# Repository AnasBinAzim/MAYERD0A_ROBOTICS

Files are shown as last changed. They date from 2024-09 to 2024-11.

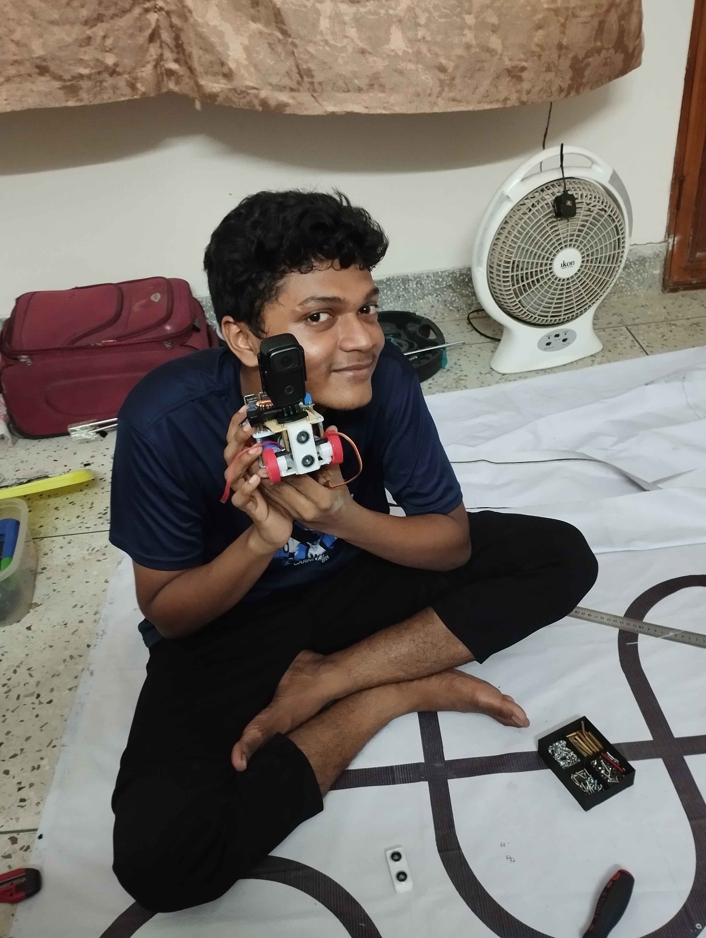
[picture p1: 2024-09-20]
other/TheEpilogue/pookie.jpg

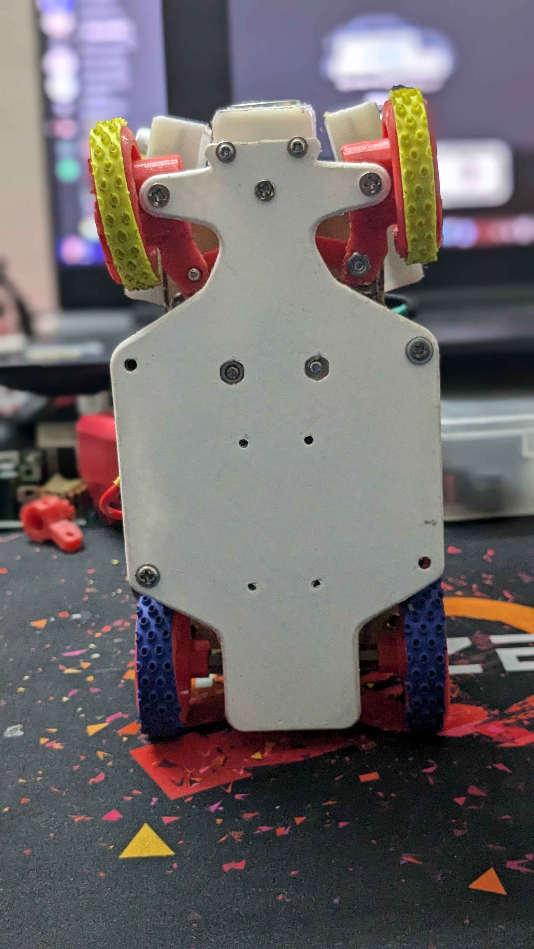
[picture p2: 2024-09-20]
v-photos/bottom_view.jpg

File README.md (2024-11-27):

# 🤖 **MAYERDOA Robotics - WRO 2024 Project** 🤖

<div align="center">
  
</div>

---

## 👥 **Team MAYERDOA - "Mothers' Prayers"**

- **Anas Bin Azim**  – Software & Hardware Developer | [anas.azim.71@gmail.com](mailto:anas.azim.71@gmail.com)
- **Rakibul Islam**  – Team Leader, Primary Hardware Developer | [rakibul.rir06@gmail.com](mailto:rakibul.rir06@gmail.com)
- **Mohiuddin Sami** – Primary Software Developer | [sm.mohiuddin.sami@gmail.com](mailto:sm.mohiuddin.sami@gmail.com)

**Team Origin**: Bangladesh

---

### 🌟 **The Meaning Behind MAYERDOA**

Our team name, "MAYERDOA," means "Mother's Prayers" in Bengali, honoring the constant support and encouragement of our mothers. From the early stages of selection to reaching the global WRO stage, they have been our strongest supporters, always standing by us. Their love and prayers have been our strength, helping us overcome challenges, achieve milestones, and stay motivated through every step of the journey. This project is more than just a technical effort—it’s a reflection of their unwavering belief in us.

---

## 🎉 Project Overview
SMOKI

This repository includes all files, designs, and code for **SMOKI**, our WRO 2024 robot. Below is the folder structure:

## 📂 Structure

Here’s a breakdown of the project folders:

- **[`Software-Setup`](./Software-Setup/)**: Steps for software and hardware setup.
- **[`experiments`](./experiments/)**: Documentation of trials and iterations with previous models.
- **[`models`](./models/)**: Contains 3D models and CAD designs.
- **[`other`](./other/)**: Additional documents and miscellaneous files.
- **[`schematic`](./schematic/)**: Wiring and circuit design diagrams.
- **[`src`](./src/)**: Source code for robot programming.
- **[`t-photos`](./t-photos/)**: Technical images of the robot build.
- **[`v-photos`](./v-photos/)**: Visual photos for aesthetics and showcasing.
- **[`video`](./video/)**: Performance and demo videos of SMOKI.

---

----

## Table of Contents

- <span style="color:blue;">Team MAYERDOA - "Mothers' Prayers"</span>
- <span style="color:green;">Mission Overview for WRO Future Engineers Rounds</span>
- <span style="color:orange;">Components and Hardware</span>
- <span style="color:purple;">Assembly Instructions</span>
- <span style="color:red;">Project Objective</span>
- <span style="color:teal;">Mobility Management</span>
- <span style="color:navy;">Power and Sense Management</span>
- <span style="color:brown;">Program Infrastructure and Explanation of Algorithm</span>
- <span style="color:darkgreen;">Software Setup</span>

Our bot, **SMOKI**, is built for excellence in the **World Robot Olympiad 2024** in the Future Engineers category. From its structural core using LEGO Technic elements to its computing capabilities powered by the **Raspberry Pi 4B** and **ESP32 microcontroller**, SMOKI is crafted to handle the nuanced challenges of autonomous navigation and obstacle handling.

---

### Mission Overview for WRO Future Engineers Rounds

<table>
  <tr>
    <td width="50%" valign="top" align="left">
      <h3>🏁 Round 1: Lap Completion</h3>
      <p>In <strong>Round 1</strong>, the robot must autonomously complete <strong>three laps</strong> on a pre-defined track. The goal of this round is for the bot to demonstrate stable navigation and precise lap tracking without any obstacle avoidance requirements.</p>
      <ul>
        <li><strong>Objective</strong>: Complete three laps on the track within the allotted time.</li>
        <li><strong>Key Tasks</strong>: Accurate path-following, speed control, and lap counting.</li>
      </ul>
      <div align="center">
        <br><br><br><br><br>
        Round 1 WRO Track
      </div>
    </td>
    <td width="50%" valign="top" align="left">
      <h3>🏆 Round 2: Lap Completion with Obstacle Avoidance and Parking</h3>
      <p>In <strong>Round 2</strong>, the bot must complete <strong>three laps</strong> while avoiding green and red obstacles:</p>
      <ul>
        <li><strong>Green Obstacles</strong>: The bot should move <strong>left</strong> to avoid.</li>
        <li><strong>Red Obstacles</strong>: The bot should move <strong>right</strong> to avoid.</li>
      </ul>
      <p>After completing the laps, the bot must accurately park within a designated zone.</p>
      <ul>
        <li><strong>Objective</strong>: Complete three laps, avoid obstacles, and park in the designated area.</li>
        <li><strong>Tasks</strong>: Obstacle detection, color-based avoidance, and precision parking.</li>
      </ul>
      <div align="center">
        Round 2 WRO Track
      </div>
    </td>
  </tr>
</table>

---
>[!IMPORTANT]
>**Important: WRO Future Engineers Rulebook**
>* **Thorough Reading:** Ensure that you thoroughly read the **WRO Future Engineers 2024 Rulebook** to understand all rules and guidelines.
>* **Official Link:** Access the rulebook here: [🔗 WRO Future Engineers 2024 Rulebook](https://wro-association.org/competitions/future-engineers/).

---
---

## 🧩 Components and Hardware

Our bot is equipped with various components that support its autonomous functionality. Here is a breakdown of the key hardware elements used in this project:

| Component | Description | Image | Purchase Link |
|---|---|---|---|
| **Raspberry Pi 4B** | Provides processing power for control algorithms and sensor data management. | <div align="center">Raspberry Pi 4B</div> | [Purchase Raspberry Pi 4B](https://amzn.to/3wKg5TG) |
| **ESP32 Microcontroller** | Handles real-time sensor data interpretation and motor control. | <div align="center">ESP32</div> | [Purchase ESP32](https://amzn.to/3ESP32) |
| **LEGO EV3 Expansion Set (45560)** | Modular components used for building and structural support. | <div align="center">LEGO EV3 Set</div>  | [Purchase LEGO 45560](https://amzn.to/3K4eLEGO) |
| **XL4016 Buck Converter** | Provides stable voltage for the Raspberry Pi and ESP32, enhancing power management. | <div align="center">XL4016 Buck Converter</div> | [Purchase XL4016](https://amzn.to/4xl4016) |
| **Custom PCB** | Custom-designed PCB for efficient wiring and stable connections across all components. | <div align="center">Custom PCB</div> | N/A |
| **Ultrasonic Sensors** | Detects distances to obstacles and aids in precise navigation. | <div align="center">Ultrasonic Sensor</div> | [Purchase Ultrasonic Sensor](https://amzn.to/3Ultrasonic) |
| **Webcam - FIFINE K420 HD** | Captures visual data, supporting navigation and obstacle detection tasks. | <div align="center">FIFINE K420 HD Webcam</div> | [Purchase FIFINE K420 HD Webcam](https://amzn.to/3FifineK420) |
| **Gyroscope - MPU 6050** | Provides motion tracking and orientation data, enabling stable navigation and movement. | <div align="center">MPU 6050</div> | [Purchase MPU 6050](https://amzn.to/3MPU6050) 
| **Battery - GENS 1000mAh** | Supplies power to the robot, ensuring long operational time and reliable energy for all components.|  | [Buy GENS ACE 11.1V 3S LiPo Battery](https://www.rcshopbd.com/product/gens-ace-11-1v-3s-lipo-1000mah-1650mah-2200mah-3300mah-battery/)

---

## 🚀 Key Features

- **Modular LEGO Design**: Easily reconfigurable using LEGO Technic parts, allowing for quick adjustments.
- **Advanced Processing with Raspberry Pi 5**: Enables complex algorithms and sensor data handling.
- **Efficient Power Management**: The XL4016 buck converter and custom PCB provide stable voltage.
- **Comprehensive Sensor Suite**: Includes ultrasonic and infrared sensors for precision navigation.
- **3D Printed Mounts**: Ensures stable and adaptable sensor and component placement.

---

## 🔧 Assembly Instructions

### 🏗️ Chassis Assembly - LEGO 45560 Expansion Set

Our robot’s chassis is built using components from the **LEGO Technic Expansion Set 45560**. This set provides modular, robust, and flexible building parts that are ideal for constructing a stable and durable chassis foundation. The combination of LEGO’s high-quality materials and custom components ensures that our robot is adaptable, allowing for quick adjustments and additions.

#### 📘 LEGO 45560 Expansion Set Manual
For a step-by-step guide on using the LEGO 45560 parts, refer to the official **LEGO 45560 Expansion Set Manual**:
- **[LEGO 45560 Expansion Set Manual (PDF Download)](https://www.lego.com/cdn/manuals/45560.pdf)**

---

#### 🧩 Parts List - LEGO 45560 Expansion Set

The LEGO 45560 Expansion Set contains a variety of parts that are essential for building complex mechanisms. Below is a detailed list of all parts included in the set:

| Part Number | Part Name | Quantity |
|---|---|---|
| 45502 | LEGO Technic Beam 3x5 | 2 |
| 45503 | LEGO Technic Beam 3x7 | 4 |
| 45504 | LEGO Technic Beam 5x11 | 2 |
| 45505 | LEGO Technic Beam 5x7 | 4 |
| 45507 | LEGO Technic Beam 1x9 | 6 |
| 45508 | LEGO Technic Beam 1x15 | 4 |
| 45509 | LEGO Technic Angular Beam 4x6  | 6 |
| 45510 | LEGO Technic Angular Beam 3x5  | 4 |
| 3703 | LEGO Technic Beam 1x16 | 2 |
| 32000 | LEGO Technic Brick 1x14 | 4 |
| 32002 | LEGO Technic Cross Block 3x3 | 4 |
| 92907 | LEGO Technic Axle 7 | 8 |
| 32009 | LEGO Technic Axle 9 | 4 |
| 24316 | LEGO Technic Gear 24 Tooth | 4 |
| 42003 | LEGO Technic Gear 16 Tooth | 6 |
| 6538b | LEGO Technic Connector Peg w/ Friction | 50 |
| 3647 | LEGO Technic Gear 8 Tooth | 6 |
| 87083 | LEGO Technic Pin 2L | 60 |
| 32269 | LEGO Technic Connector Peg | 20 |
| 40490 | LEGO Technic Axle Pin | 40 |
| 32556 | LEGO Technic Double Cross Block | 6 |
| 32184 | LEGO Technic Connector with Bush | 8 |
| 3749 | LEGO Technic Bush | 40 |
| 3713 | LEGO Technic Half Bush | 30 |
| 42195 | LEGO Technic Pin w/ Stop | 12 |
| 18654 | LEGO Technic Angular Beam 4x4  | 6 |
| 11478 | LEGO Technic Frame 5x7 | 2 |

> **Note**: Quantities are approximate based on the LEGO 45560 set contents. For exact counts, refer to the [manual](https://www.lego.com/cdn/manuals/45560.pdf).

---

#### 🛠️ Chassis Assembly Process

Here’s a step-by-step overview of the chassis assembly process using the LEGO 45560 Expansion Set:

1. **Base Frame Construction**: Start by assembling the base frame using 5x11 and 5x7 beams for structural stability. These beams provide a strong foundation for mounting additional components.
2. **Motor and Axle Integration**: Utilize the LEGO Technic beams and axle connectors to securely attach the motors. Ensure proper alignment to enable smooth and controlled movement.
3. **Reinforcing with Angular Beams**: Use the 4x6 and 3x5 angular beams to reinforce corners and support areas where weight and stress are concentrated.
4. **Mounting Sensors and Electronics**: Attach sensor mounts and electronic components using cross blocks and bushings, making sure they are aligned for efficient data capture and processing.
5. **Gear Assembly for Differential Drive**: Assemble gears (8, 16, and 24-tooth gears) to create a differential drive system, allowing independent rotation of wheels for smooth turns.

---

#### 🔍 Benefits of Using LEGO Technic Parts

- **Modularity**: The LEGO Technic beams and connectors allow for quick modifications, so adjustments can be made without disrupting the entire structure.
- **Durability**: High-quality materials ensure the chassis remains stable even during rigorous testing.
- **Precision**: Technic gears, axles, and connectors provide precise alignment, which is critical for movement control and sensor accuracy.

---

By leveraging the flexibility and durability of the LEGO 45560 Expansion Set, our chassis design achieves a balance between robustness and adaptability. The manual and parts list serve as valuable resources for replicating or modifying the design as needed.

---

The following images showcase the detailed assembly process of our WRO Bot's chassis, utilizing the LEGO 45560 expansion set.

<!DOCTYPE html>
<html lang="en">
<head>
  <meta charset="UTF-8">
  <meta name="viewport" content="width=device-width, initial-scale=1.0">
</head>
<body>
  <table style = "width:100%; border-collapse:collapse">
    <caption><strong>Framed Images</strong></caption>
    <tr>
      <td></td>
      <td></td>
    </tr>
    <tr>
      <td></td>
      <td></td>
    </tr>
    <tr>
      <td></td>
      <td></td>
    </tr>
    <tr>
      <td colspan="2"></td>
    </tr>
  </table>
</body>
</html>

### 🚗 Drive System

The drive system includes DC motors, which provide reliable propulsion and control.

<p align="center">
  <table>
    <tr>
      <td>
        
      </td>
      <td>
        
      </td>
    </tr>
    <tr>
      <td>
        
      </td>
      <td>
        
      </td>
    </tr>
  </table>
</p>

----

# 🚗 Mobility Management

This segment goes over the mobility management of SMOKI
---

### **Rear Axle Power Distribution**

Initially, the rear wheels were powered through a **Bevel Gear**, but we later upgraded to a **Differential Gearbox** to improve efficiency and performance during turns.

---

#### **Bevel Gear**

<table>
<tr>
<td width="50%">
<div align="center">
  
</div>
</td>
<td width="50%">

A **bevel gear** is a type of gear where the axes of the two shafts intersect, and the tooth-bearing faces of the gears are conical. Bevel gears are commonly used to transfer motion between intersecting shafts at an angle, typically 90°.

##### **How Bevel Gears Work**
- A driver gear transfers motion to a driven gear, which rotates an output shaft.
- The teeth of the gears are designed to mesh smoothly, transferring torque efficiently between the shafts.

##### **Advantages of Bevel Gears**
1. **Compact Design**: Suitable for space-constrained applications.
2. **Efficient Torque Transfer**: Provides reliable power transmission at angles.
3. **Versatility**: Can operate at angles other than 90° if needed.

</td>
</tr>
</table>

---
>[!IMPORTANT]
> Bevel gears were essential in the initial stages of our design, but they had limitations in terms of energy efficiency during turns.
---

#### **Differential Gearbox**

<table>
<tr>
<td width="50%">

A **differential gearbox** allows the wheels on the same axle to rotate at different speeds while receiving power from a single motor. This is crucial for smooth turning, where the outer wheel must travel a larger distance than the inner wheel.

##### **Advantages of Differential Gearbox**
1. **Smooth Turns**: Adapts to varying wheel speeds, ensuring efficient cornering.
2. **Energy Efficiency**: Reduces energy wastage by minimizing wheel slippage.
3. **Component Longevity**: Minimizes wear on tires and axles.

##### **How Differential Gears Work**
- Power from the motor is delivered to an input shaft.
- The differential splits the torque between the two wheels via bevel or spider gears inside the housing.
- During turns, the differential allows one wheel to spin faster than the other, ensuring smooth movement.

</td>
<td width="50%">
<div align="center">
  
</div>
</td>
</tr>
</table>

---

#### **Comparison: Bevel Gear vs. Differential Gearbox**

| **Feature** | **Bevel Gear** | **Differential Gearbox** |
|---|---|---|
| **Turning Efficiency** | Limited; fixed wheel speeds. | Superior; wheels rotate independently. |
| **Energy Usage** | Higher due to slippage during turns. | Lower; optimized for dynamic turns. |
| **Durability** | Higher strain on components. | Reduced strain; longer component life. |

---

### **Servo Motor with L293D Motor Driver**

<table>
<tr>
<td width="30%">
<div align="center">
  
</div>
</td>
<td width="70%">

We used the **L293D Motor Driver** in combination with a **Servo Motor** to control the robot's wheels effectively. We are using **L293D Motor Driver** to control the rear axle motor. The L293D is a dual H-Bridge motor driver that is perfectly suited for the LEGO motor, which operates at **750mA** current.

##### **Why L293D?**
- **Optimal Current Capacity**: Can handle up to **1A** peak current, suitable for the LEGO motor’s 750mA requirement.
- **Bidirectional Control**: Facilitates forward and backward motion of the wheels.
- **Compact and Lightweight**: Ideal for small-scale robotic systems.
- **PWM Support**: Enables smooth speed control of the motors.

##### **Advantages of the Servo Motor with L293D**
1. **Accurate Steering**: The servo motor ensures precise angle adjustments.
2. **Smooth Speed Control**: PWM functionality provides variable speed control.
3. **Efficient Current Management**: Matches the LEGO motor's current needs, ensuring reliable operation.

</td>
</tr>
</table>

---

### **Steering Systems**

Our robot initially used the **Ackermann Steering System**, known for its efficiency in real-world vehicles. However, we later transitioned to the **LEGO Steering System** to simplify the design and improve modularity while maintaining effective steering control.

---

#### **What is Ackermann Steering System?**

The **Ackermann Steering System** ensures that the wheels of a vehicle turn at different angles during a corner. The inner wheels turn more sharply than the outer wheels, reducing tire slippage and allowing smooth, efficient turning.

##### **How Ackermann Steering Works**
- The front wheels are connected via a set of steering arms.
- These arms are angled so that their lines meet at the center of the turn’s radius, ensuring concentric paths for all wheels.

##### **Advantages of Ackermann Steering**
1. **Efficient Turning**: Minimizes tire slippage.
2. **Energy Savings**: Reduces power loss caused by wheel drag.
3. **Realistic Simulation**: Mirrors real-world vehicle steering.

---

#### **Why We Switched to LEGO Steering System**

The **LEGO Steering System** offered greater simplicity and modularity, which were critical for our robot’s design. While Ackermann Steering is ideal for large-scale vehicles, the LEGO system provided better adaptability for our compact robot.

---

#### **What is LEGO Steering System?**

The LEGO Steering System uses modular LEGO Technic parts with a simple rack-and-pinion mechanism for steering. It achieves a turning angle of **50 degrees**, allowing precise control over the robot's movements.

##### **Advantages of LEGO Steering**
1. **Modularity**: Easy to assemble, adjust, and maintain.
2. **Compact Design**: Fits seamlessly into the robot’s chassis.
3. **Precision**: Allows accurate steering movements with a servo motor.
4. **Ease of Use**: Simplifies the overall system design without sacrificing functionality.

---
---

### **Conclusion**

The upgrades to our robot’s mobility system—switching from bevel gears to a differential gearbox, integrating the L293D with a servo motor, and transitioning from  a 3D printed steering mechanism to a steering mechanism using LEGO parts—significantly enhanced its performance. These changes provided:
1. **Smoother Turns**: Differential gearbox enabled independent wheel speeds, reducing slippage.
2. **Precise Control**: The L293D motor driver ensured smooth speed and direction management.
3. **Simpler Design**: LEGO Steering’s modularity allowed for easier integration and maintenance.
4. **Energy Efficiency**: Reduced strain on components, improving energy usage and longevity.

Together, these upgrades ensured that our robot was optimized for the challenges of the WRO course, achieving a balance between simplicity and performance.

----
----
----

# ⚡ Power and Sense Management :

The **Power and Sense Management** system of our robot has been meticulously designed to optimize performance while ensuring reliable power delivery, precise sensing, and efficient communication between components.

## 📜 Overview
The power system ensures all components receive stable and efficient power tailored to their unique voltage and current requirements. This design optimizes energy utilization and guarantees reliability under various operational loads.

---

## ⚙️ System Architecture

### **1. Power Source: Two Lithium-Ion Cells**
- **Configuration**: Two 4.2V lithium-ion cells connected in series.
- **Total Voltage**: 8.4V when fully charged, dropping to ~6V when discharged.
- **Features**:
  - High energy density for extended runtime.
  - Lightweight and rechargeable.

---

### **2. XL4016 Buck Converter**
- **Input**: 8.4V from the battery pack.
- **Output**: Stable 5V for the **Raspberry Pi 5** and other components.
- **Specifications**:
  - Input Voltage Range: Up to 40V.
  - High efficiency (~90%) for minimal heat generation.
- **Usage**:
  - Powers the Raspberry Pi 4B to ensure stable performance for real-time processing tasks.

---

### **3. Additional Buck Converters**
#### **(a) 5V Buck Converter for Servo Motor**
- **Purpose**: Supplies 5V for the **Servo Motor**.
- **Key Benefits**:
  - Ensures optimal torque and speed for motor operations.
  - Prevents jitter or underperformance caused by unstable power.

#### **(b) 5V Buck Converter for ESP32**
- **Purpose**: Supplies 5V for the **ESP32 Microcontroller**.
- **Features**:
  - Powers the ESP32 for communication (Wi-Fi and Bluetooth).
  - Protects against overvoltage, ensuring stable and reliable operation.

---

### **4. Buck-Boost Converter for Motors**
- **Purpose**: Provides a consistent 12V for the motors, regardless of battery voltage variations.
- **How It Works**:
  - Boosts the voltage when input drops below 12V (e.g., batteries discharged to 6V).
  - Steps down the voltage if the input exceeds 12V.
- **Benefits**:
  - Delivers reliable motor performance under various loads.
  - Prevents voltage-related motor performance issues.

---

## 🔌 Voltage Distribution Table

| Component | Voltage Supplied | Converter Type |
|---|---|---|
| **Raspberry Pi 4B** | 5V | XL4016 Buck |
| **Servo Motor** | 5V | Buck Converter |
| **ESP32 Microcontroller**| 5V | Buck Converter |
| **Motors** | 12V | Buck-Boost Converter|

---

## 🔧 Installation and Configuration

1. **Connect the Lithium-Ion Cells**:
   - Use a **series connection** to achieve 8.4V.
   - Ensure a proper battery management system (BMS) to prevent overcharging or deep discharging.

2. **Setup XL4016 Buck Converter**:
   - Adjust the output voltage to 5V using the onboard potentiometer.
   - Connect the output to the Raspberry Pi 5 power input.

3. **Install Buck Converters**:
   - **5V Converter for Servo Motor**:
     - Configure the output voltage to 5V for the servo motor.
     - Connect the output to the servo's power input.
   - **5V Converter for ESP32**:
     - Configure the output voltage to 5V for the ESP32 microcontroller.
     - Connect the output to the ESP32's power input.

4. **Configure Buck-Boost Converter**:
   - Set the output to 12V.
   - Connect the output to the motor driver’s power input.

5. **Test Voltage Levels**:
   - Use a multimeter to verify output voltages for each converter before powering the components.

---

## 🛠 Maintenance Tips
- **Regularly Check Connections**:
  - Ensure tight and secure connections to avoid power interruptions.
- **Monitor Battery Levels**:
  - Recharge the lithium-ion cells when the voltage drops below 6V.
- **Inspect Converters**:
  - Periodically check for overheating or loose components on the converters.

---

## 🚀 Future Improvements
- Integrate a smart power monitoring system to dynamically adjust power distribution.
- Upgrade to more energy-efficient components as technology advances. ( WE WILL BE AROUND HOPEFULLY)

---
## 🎥 Camera Placement and Functionality

The robot's main camera is positioned at the top and angled slightly downwards. This setup enhances object detection capabilities by providing:
- **🔍 Close-Range Detection**: The camera can identify objects in close proximity with high accuracy.
- **🌐 Extended-Range Detection**: Ensures objects further away are detected effectively.

The camera feeds data to the **Raspberry Pi 5**, which processes image recognition algorithms to detect towers and corner lines. The processed data is then transmitted to the **ESP32 microcontroller** for real-time navigation and obstacle avoidance.

---

## 📡 Sonar Mount Design

### 🛠️ Previous Design
In our earlier design, we used **HC-SR04 sonar sensors** placed at **45-degree angles**, mounted horizontally on two sides of the robot, with one sensor placed vertically in the middle. This configuration provided basic obstacle detection but had limitations:
- **🚫 Blind Spots**: The horizontal placement created gaps in detection range at certain angles.
- **⚠️ Inconsistent Readings**: The 45-degree angle sometimes caused inaccuracies due to signal reflections.

### 🔄 Why We Switched
After analyzing performance during testing, we made significant improvements:
- Replaced the 45-degree sensors with sensors mounted at **15 degrees**.
- Mounted the sensors **vertically on all sides**, ensuring:
  - **🛑 Improved Obstacle Detection**: Enhanced accuracy and coverage around the robot.
  - **📏 Better Range Consistency**: Reduced signal reflection issues for more reliable readings.

### 🚀 Current Design
The new configuration leverages **HC-SR04 sonar sensors**, chosen for their **wide availability** and **affordable price**. The updated design provides:
- **High Coverage**: Vertical mounting eliminates blind spots.
- **Early Detection**: Enhanced obstacle sensing allows for quicker decision-making.
- **Really Cheap**: You can buy 300 of these instead of a Lider Sensor.

---

>[!IMPORTANT]
> **Power Highlights:**
> - The XL4016 Buck Converter ensures stable voltage regulation, critical for protecting the Raspberry Pi and ESP32 microcontroller during operation.
> - Independent buck modules handle the servo motor and ESP32 power needs, optimizing energy usage across all components.

---
---

## 🛠️ Our PCB is custom made. The schematics are in the schematic folder 

---
# Project Name

## 🖼️ System Visuals

### PCB Views

| **Top View of PCB** | **Bottom View of PCB** |
|---|---|
|  |  |

### Power Management Diagram

DIAGRAM

---
---

# 🧠 Program Infrastructure and Explanation ## 🏁 Round 1 Algorithm - Lap Completion

In **Round 1**, our robot **SMOKI** must autonomously complete **three laps** on a predefined track without the need for obstacle avoidance. To achieve precise navigation and lap counting, we have developed a robust algorithm that integrates image processing with control systems.

---

### 🌐 Algorithm Overview

1. **📸 Image Acquisition**:
   - The robot captures real-time images of the track using its onboard camera.

2. **🎨 Color Space Conversion**:
   - Captured images are converted from the **RGB** color space to the **HSV (Hue, Saturation, Value)** color space.
   - The HSV color space is chosen for its effectiveness in color segmentation, as it is less sensitive to lighting variations.

3. **🔍 Color Segmentation and Orientation Determination**:
   - Using predetermined HSV ranges, the algorithm isolates the **blue** and **orange** line segments on the track.
   - During the first run, the robot checks whether the blue line appears before the orange line or vice versa.
   - **Orientation Determination**:
     - If the blue line comes before the orange line, the robot sets its orientation accordingly.
     - This initial orientation check ensures the robot follows the track in the correct direction.

4. **📏 Line Detection and Lap Counting**:
   - The **Hough Line Transform** method is applied to detect lines within the segmented images.
   - The robot counts the detected lines to keep track of laps.
   - **Lap Completion**:
     - After counting **12 lines** (corresponding to three laps), the robot initiates a predetermined delay and then stops.

5. **⚙️ Position Correction Using PID Control**:
   - Before setting the orientation, a **PID (Proportional-Integral-Derivative) controller** calculates the error.
   - **Error Calculation**:
     - The error is determined by the difference between the distances measured by sensors on the left and right sides of the robot (i.e., `error = left_distance - right_distance` or vice versa).
   - **Distance Maintenance**:
     - If the orientation is **right-based**, the robot maintains a **25 cm** distance from the right side.
     - If the orientation is **left-based**, it maintains a **25 cm** distance from the left side.
   - The PID controller adjusts the robot's steering to minimize the error, helping it stay centered on the track.

---

### 📖 Detailed Explanation

#### 1. 📸 Image Acquisition and Preprocessing

- **Camera Input**:
  - High-resolution images are captured at regular intervals to ensure up-to-date visual data.
- **HSV Conversion**:
  - Conversion to HSV allows for more effective color thresholding.
  - HSV separates image intensity (Value) from color information (Hue and Saturation), making it easier to detect specific colors under varying lighting conditions.

#### 2. 🎨 Color Segmentation

- **HSV Thresholding**:
  - Specific HSV ranges for blue and orange are defined based on calibration.
  - **Blue Line Detection**:
    - Pixels within the blue HSV range are extracted.
  - **Orange Line Detection**:
    - Pixels within the orange HSV range are extracted.
- **Orientation Check**:
  - By analyzing the sequence of color segments (blue vs. orange), the robot determines its starting orientation.
  - This prevents incorrect lap counting due to starting in the wrong direction.

#### 3. 📏 Line Detection with Hough Transform

- **Edge Detection**:
  - Preprocessing steps like Gaussian blur and Canny edge detection are applied to enhance line features.
- **Hough Line Transform**:
  - Detects straight lines by transforming points in image space to a parameter space.
  - Lines are identified based on the accumulation of intersecting points in the parameter space.
- **Lap Counting Logic**:
  - Each detected line crossing increments a counter.
  - The robot recognizes lap completion after counting **12** line crossings, accounting for both blue and orange lines over three laps.

<div align="center">
  <!-- Placeholder for Hough Line Transform Image -->

  Hough Line Transform
  <p><em>Figure: Visualization of Hough Line Transform applied to track image.</em></p>
</div>

#### 🔗 **Hough Line Transform Tutorial**

For a comprehensive understanding of the Hough Line Transform method, you can watch this detailed tutorial:

- [🔗 Hough Line Transform Tutorial by DigitalSreeni](https://www.youtube.com/watch?v=5zAT6yTHvP0&ab_channel=DigitalSreeni)

#### 4. ⚙️ PID Control for Position Correction

- **Sensor Input**:
  - Distance sensors on both sides provide real-time measurements of the robot's position relative to the track edges.
- **Error Calculation**:
  - The error signal is the difference between the left and right distance measurements.
- **PID Controller**:
  - **Proportional Term (P)**: Reacts to the current error.
  - **Integral Term (I)**: Accounts for past errors to eliminate steady-state offset.
  - **Derivative Term (D)**: Predicts future error based on the rate of change.
- **Steering Adjustment**:
  - The PID output adjusts the steering angle to minimize the error.
  - Ensures the robot maintains the desired **25 cm** distance from the designated side.
- **Orientation-Based Behavior**:
  - **Right-Based Orientation**:
    - The robot favors the right side of the track.
  - **Left-Based Orientation**:
    - The robot favors the left side of the track.

---

### 📊 Flowchart of the Algorithm

## 📊 Flowchart of the Algorithm

```mermaid
flowchart TD
    A[Start] --> B[Capture Image]
    B --> C[Convert to HSV]
    C --> D[Segment Blue and Orange Portions]
    D --> H[Apply Hough Line Transform]
    H --> E{Blue Before Orange?}
    E -->|Yes| F[Set Right-Based Orientation]
    E -->|No| G[Set Left-Based Orientation]
    F --> I[Count Detected Lines]
    G --> I
    I --> J{Lines Counted >= 12?}
    J -->|No| K[Calculate Error]
    K --> L[PID Controller Adjusts Steering]
    L --> M[Continue Navigation]
    M --> B
    J -->|Yes| N[Delay and Stop]
    N --> O[End]
```
---

# 🏆 Round 2 Algorithm - Lap Completion with Obstacle Avoidance and Object Detection

Round 2 involves an enhanced version of our robot SMOKI, which autonomously completes three laps, avoiding obstacles and calculating the steering value based on object prioritization and boundary detection. Below is an in-depth look at the step-by-step algorithm implemented for this round.

## 🌟 Step-by-Step Algorithm Overview

### 📸 Image Acquisition:
- The camera captures real-time images of the track and surroundings.

### 🎨 HSV Color Conversion:
- Convert the captured image from RGB to HSV (Hue, Saturation, Value) scale.
- Store all relevant line and object colors for further use.

### 💨 Gaussian Blur:
- Apply Gaussian Blur to the frame to reduce noise.
- Based on predetermined HSV range, isolate the black border portion.

### ⚫ Black Border Detection:
- Use Canny Edge Detection to identify the black border walls.
- Apply Hough Line Probabilistic Transformation to determine acceptable border walls.

### 🛑 Border Masking:
- Create a border in the frame based on the detected lines.
- Mask out everything beyond the border to eliminate unnecessary information for the rest of the algorithm.

### 🔍 Line Detection (Blue or Orange):
- Identify lines using the predetermined HSV color range.
- Check for the blue or orange line in the frame.

### 📐 Slope Calculation:
- If a line is found, calculate the minimum and maximum slopes for both the blue and orange lines (if both are present).

### ↩️ Orientation Determination:
- If both blue and orange lines are detected, compare their slopes.
- Determine the clockwise or anti-clockwise orientation and store this in a variable for future reference.

### 📊 Object Detection and Prioritization:
- Detect acceptable objects within the boundary wall.
- Assign a priority value to each object based on distance, orientation, and coordinates.
- Register only one object based on predetermined mathematical calculations.
- Calculate the steering value for navigation using a quadratic function based on the object's distance and position along the x-axis.

### 📡 Serial Communication:
- Send the calculated steering value to the ESP32 via serial communication to adjust the robot's movement accordingly.

---

## Algorithm Explanation

- **HSV Conversion** allows for effective color segmentation, making it easier to distinguish between track lines and other features regardless of lighting conditions.
- **Gaussian Blur** helps to reduce noise, making the detection of borders and lines more reliable.
- Using **Hough Line Transform** and **Canny Edge Detection** enables accurate identification of boundaries, which is crucial for masking irrelevant parts of the frame.
- **Slope Comparison** provides the robot with information about its current orientation, enabling it to differentiate between clockwise and anti-clockwise directions based on the detected lines.
- The **Object Prioritization** mechanism ensures that the robot only reacts to the most relevant obstacle, improving navigation efficiency.
- Finally, the calculated steering value is sent to the ESP32 for precise movement control, ensuring that the robot maintains its intended path while avoiding obstacles effectively.

## Video Tutorial for Hough Line Transform

For a better understanding of how the Hough Line Transform method is used in our algorithm, you can watch this detailed video tutorial:

- [🔗 Hough Line Transform Tutorial by DigitalSreeni](https://www.youtube.com/watch?v=6-3HgNZkDGA)

## Next Steps

- Test the algorithm in various track conditions to ensure robustness.
- Fine-tune the HSV color ranges and quadratic function for steering to achieve optimal performance.
- Collect data on the robot's performance to further refine the object prioritization logic.

Feel free to reach out if you need more insights or help with further tuning the algorithm!

## **Flowchart**

```mermaid
flowchart TD
    Start --> Step1[Capture Image]
    Step1 --> Step2[Convert Image to HSV]
    Step2 --> Step3[Apply Gaussian Blur]
    Step3 --> Step4[Isolate Black Borders]
    Step4 --> Step5[Detect Borders with Canny Edge and Hough Transform]
    Step5 --> Step6[Mask Area Outside Borders]
    Step6 --> Step7[Detect Blue or Orange Lines]
    Step7 --> Step8[Calculate Min and Max Slopes]
    Step8 --> Decision1{Both Lines Detected?}
    Decision1 -- Yes --> Step9[Determine Orientation]
    Decision1 -- No --> Step9[Use Detected Line]
    Step9 --> Step10[Detect Objects Within Boundary]
    Step10 --> Step11[Assign Priority to Objects]
    Step11 --> Step12[Select Highest Priority Object]
    Step12 --> Step13[Calculate Steering Value]
    Step13 --> Step14[Send Steering Value to ESP32]
    Step14 --> End

```

---
---
<p align="center">
  # THATS ALL FROM US
</p>



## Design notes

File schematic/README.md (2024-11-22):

# SMOKI's PCB Schematic Diagram :



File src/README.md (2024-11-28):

#Thesecond round code is in WRO_int_2nd_finalV1.zip

# Source Code 🧑‍💻
This repository contains the core source code for **SMOKI**, our competition robot. It includes:

- **Arduino code** for motor and sensor control 🚗💡
- **OpenCV** implementation for color and line detection 🎨📸

---

Arduino and SMOKI Setup

### Arduino in Action 🛠️
In the **Future Engineers** category of the **World Robotics Olympiad (WRO)**, Arduino plays a vital role in controlling our robot's movements and interacting with the environment. Here's how we use it:

#### Key Features:
- **Sensor Integration**: Arduino reads from ultrasonic, infrared, and other sensors to help SMOKI perceive its surroundings. 📡
- **Motor Control**: It handles motor speed and direction, allowing for precise movement and obstacle avoidance. 🚗
- **Autonomous Navigation**: We implement path-following algorithms for SMOKI to navigate autonomously. 🤖
- **Customization**: Code optimizations enhance performance, improving SMOKI’s chances in the competition. ⚙️✨

---

OpenCV Color Detection

### OpenCV & Color Detection 🎨
In **SMOKI**, **OpenCV** is used extensively for detecting objects and lines by color. Below are key processes and how they work in our robot:

1. **Color Space Conversion**: Convert RGB to HSV to isolate colors more effectively. 🌈
2. **Color Thresholding**: Identify specific color ranges (green, red, etc.) using masks. 🎯
3. **Contour Detection**: Find the shape and size of detected objects based on the masks. 🔍
4. **Hough Line Transform**: Used for blue line detection to navigate paths. 📏
5. **Object Tracking**: Real-time tracking of colors and lines, crucial for dynamic navigation. 🔄

---

Object Color Detection

By integrating Arduino and OpenCV, **SMOKI** is capable of advanced color detection and navigation, making it a strong contender in the WRO competition. 🚀

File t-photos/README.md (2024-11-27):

# **This folder contains photos of our team MAYERDOA_ROBOTICS.**

Team_Photo_MAYERDOA_ROBOTICS 1

candid

LASTSECONDCOOKING(funny photo)

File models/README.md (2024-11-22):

# 🤖 **SMOKI - STL Files Repository**

This repository contains the 3D models and components used in building **SMOKI**, a robot developed by **MAYERDOA ROBOTICS**. These files are essential for replicating or learning from our design process.

---

## 📂 **Available STL Files**

Here’s a quick overview of the 3D models included in this repository:

- **[Buck Module Holder](./Buck%20module%20holder.stl)**: Securely holds the buck module in place.
- **[Servo and Steering Shaft Connector](./Servo%20and%20sttering%20shaft%20connector.stl)**: Connects the servo to the steering shaft for precise movements.
- **[Battery Case](./battery%20case%20%281%29.stl)**: Houses and secures the battery module.
- **[Front Sonar Mount](./front_sonar%20mount.stl)**: Mount for the front sonar sensor to enhance obstacle detection.
- **[Pi 4 Mount](./pi%204%20mount.stl)**: Provides a stable base for the Raspberry Pi 4 board.
- **[Servo and Camera Attach](./servo%20and%20camera%20atttach.stl)**: Holds the servo and camera module for vision-based tasks.
- **[Side Sonar Mount](./side%20sonar%20mount.stl)**: Holds sonar sensors for side obstacle detection.
- **[Steering Shaft](./sttering%20shaft.stl)**: Part of the steering mechanism for dynamic control.

---

## 🔧 **Bot Structure**

The structure of **SMOKI** is primarily built using **LEGO components** for modularity and easy prototyping. Therefore, this repository contains fewer 3D models, focusing only on the essential custom components.

---

## 📌 **Usage Instructions**

1. **Download the STL Files**: Click on the links above to download individual files or clone the repository to access all files.
2. **3D Printing**: The printer we are using is **Ender 3 S1 Pro**. Print the models using your preferred 3D printer and settings. We recommend high-strength PLA or PETG for durability.  

   <p align="center">
      Ender 3 S1 Pro 3D Printer
   </p>

3. **Assembly**: Follow the [Robot Assembly Guide](../README.md) in the main repository for detailed instructions on integrating these components into the robot.

---

---

---

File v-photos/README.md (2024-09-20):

# Vehicle Photos
This folder contains photos of the robot from all required directions.

* `Front.jpg`: Front view of the robot.
* `Back.jpg`: Back view of the robot.
* `Top.jpg`: Top view of the robot.
* `Bottom.jpg`: Bottom view of the robot.
* `Left.jpg`: Left view of the robot.
* `Right.jpg`: Right view of the robot.

| Front | Back |
| --- | --- |
| front | back |

| Top | Bottom |
| --- | --- |
| top  | bottom |

| Left | Right |
| --- | --- |
| left  | right |

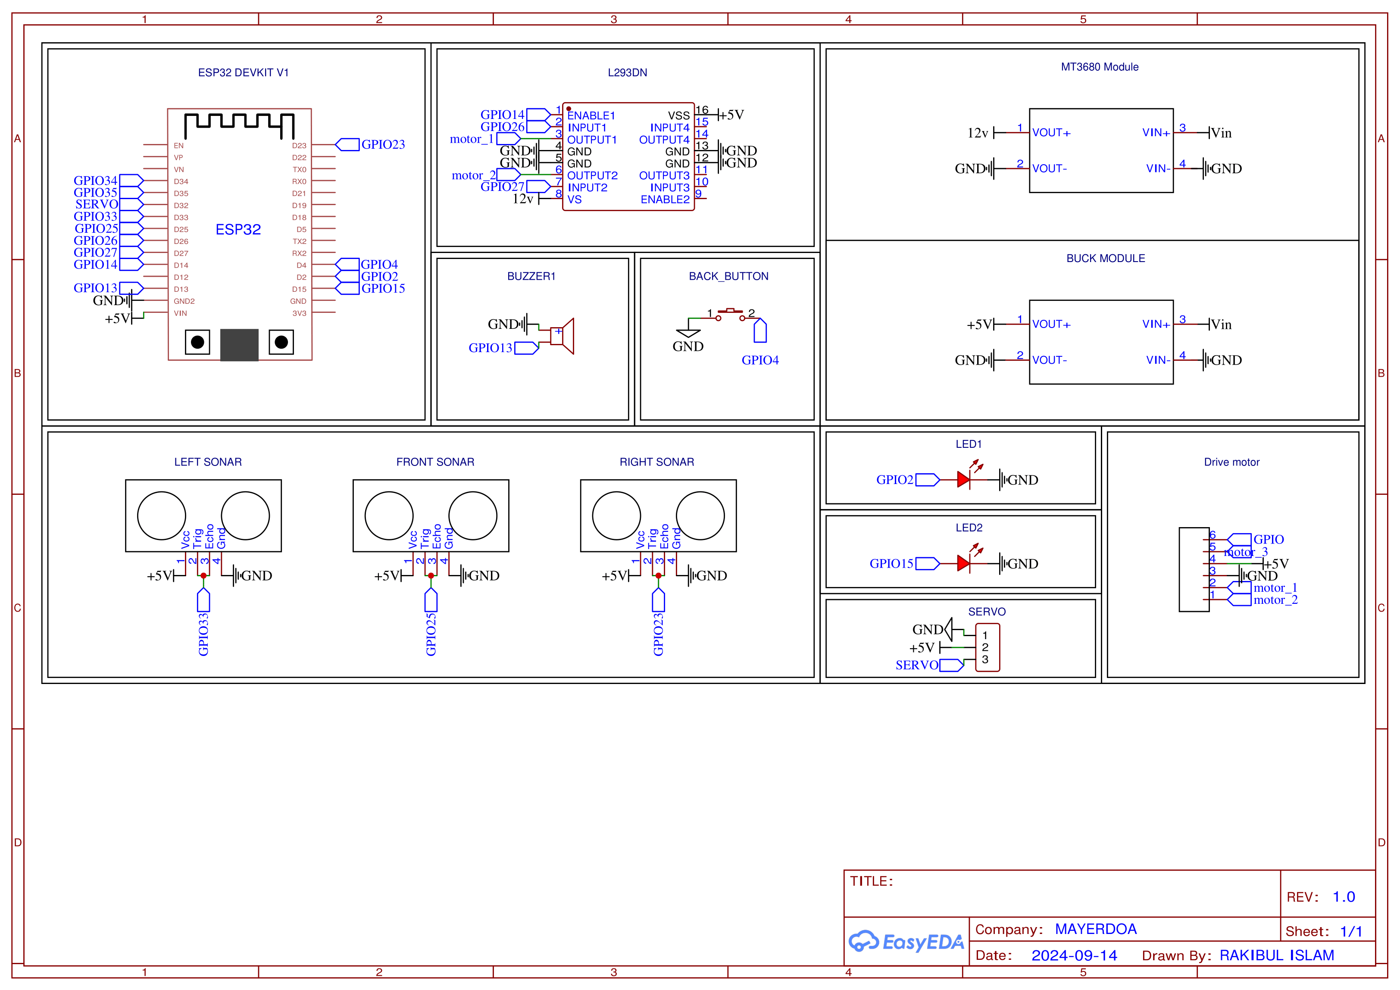
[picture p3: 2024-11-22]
schematic/smoki_schematic_preview.png

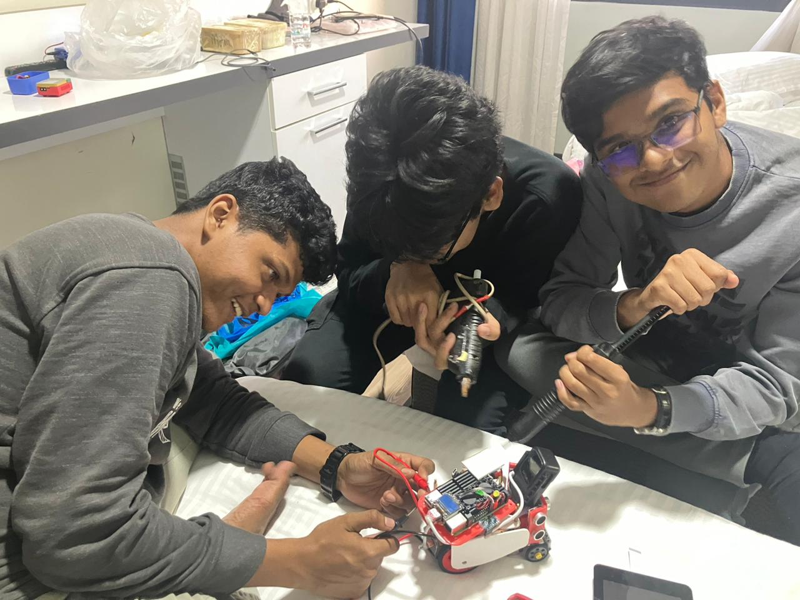
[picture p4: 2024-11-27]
t-photos/funnyteamphoto/LASTSECONDCOOKING(funny photo).jpg

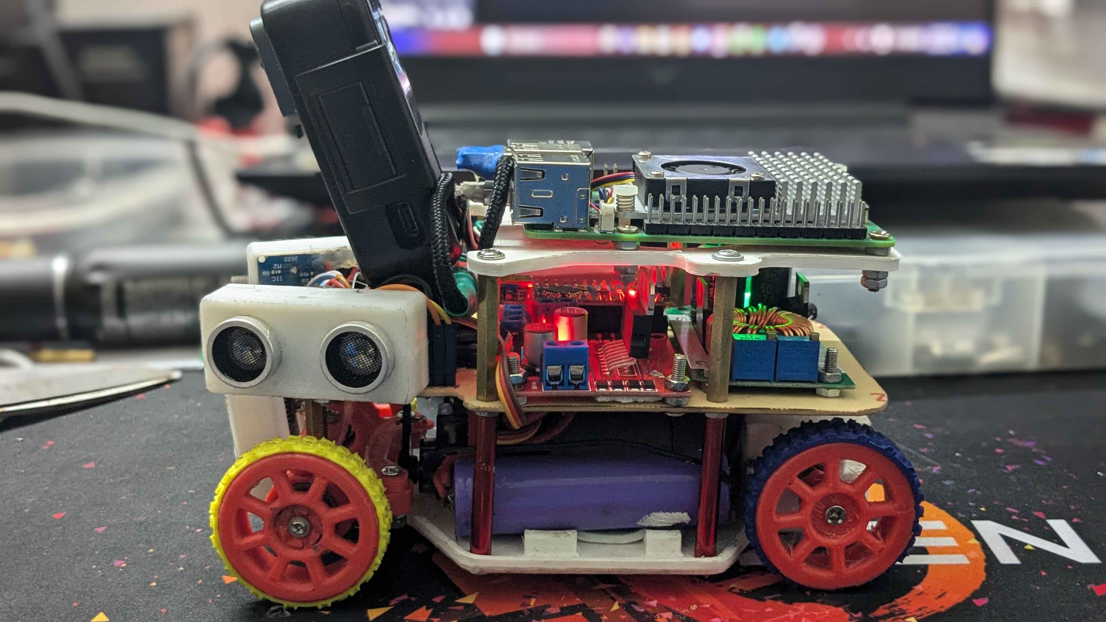
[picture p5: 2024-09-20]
v-photos/left_view.jpg

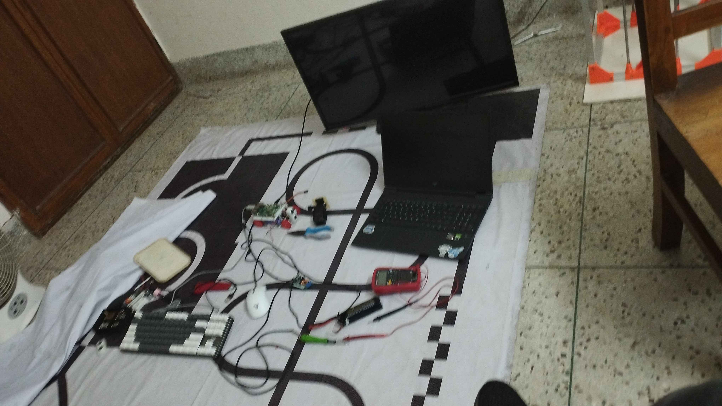
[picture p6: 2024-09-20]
other/TheEpilogue/WIRED.jpg

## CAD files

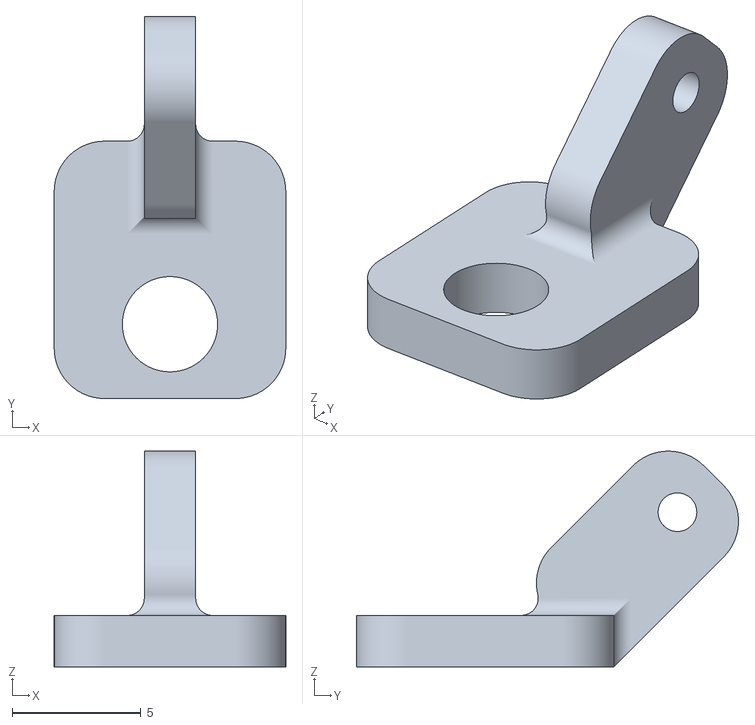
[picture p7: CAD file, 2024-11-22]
models/sttering shaft.stl
9.00 x 14.8 x 8.38

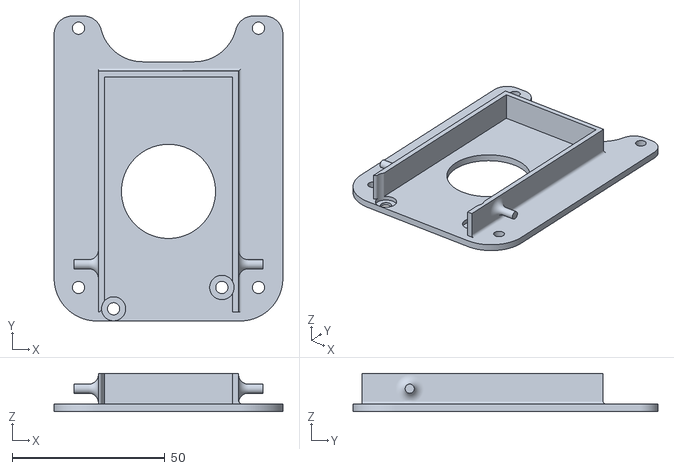
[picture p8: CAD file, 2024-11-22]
models/battery case (1).stl
75.0 x 100.0 x 12.5

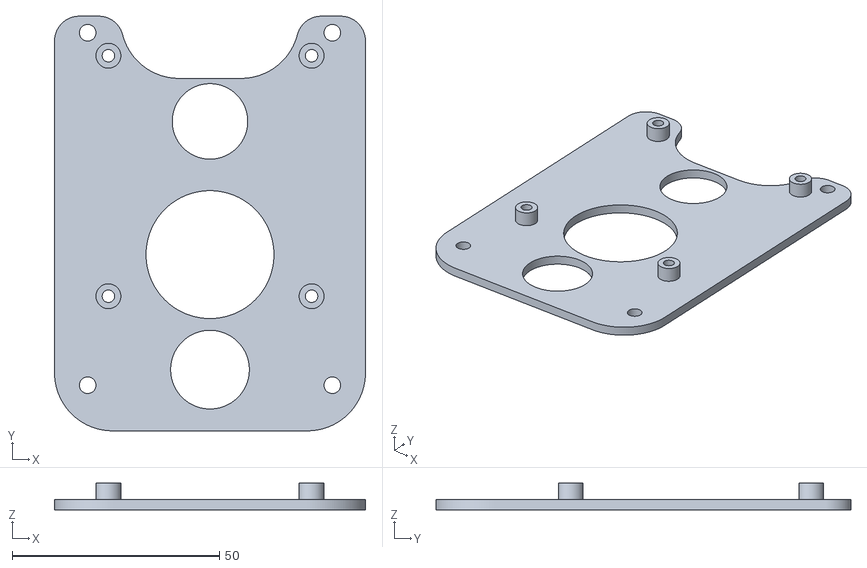
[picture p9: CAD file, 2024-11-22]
models/pi 4 mount.stl
75.0 x 100.0 x 6.50

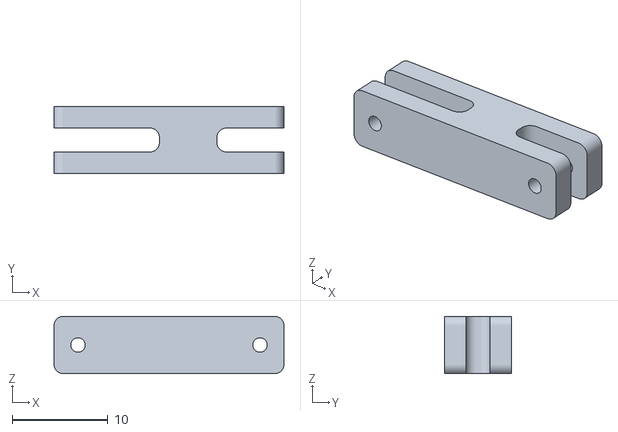
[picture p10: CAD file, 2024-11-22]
models/Servo and sttering shaft connector.stl
24.0 x 7.00 x 6.00

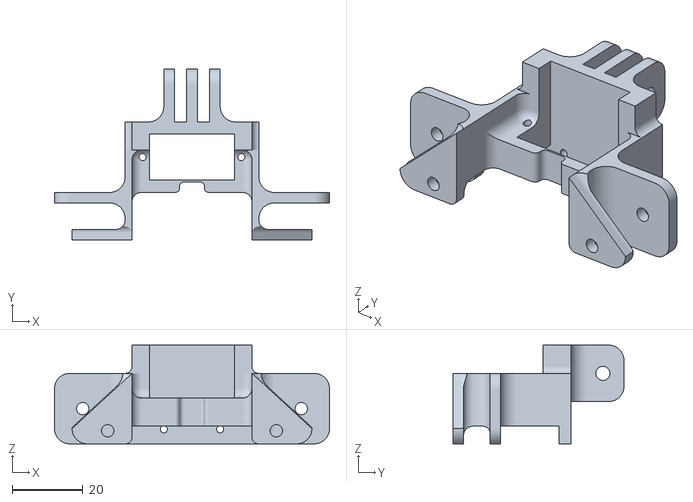
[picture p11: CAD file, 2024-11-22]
models/servo and camera atttach.stl
78.0 x 48.5 x 28.0

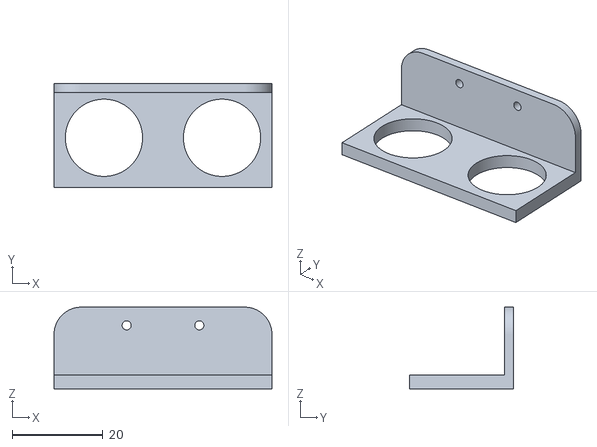
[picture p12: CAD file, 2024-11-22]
models/front_sonar mount.stl
48.0 x 23.0 x 18.0

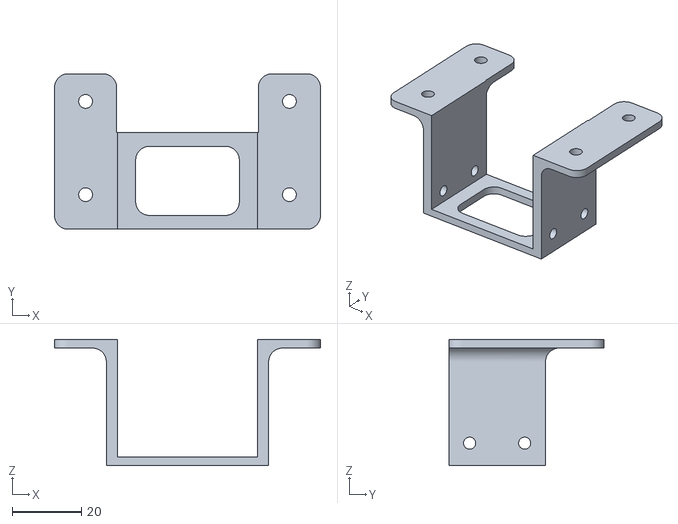
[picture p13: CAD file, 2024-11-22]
models/Buck module holder.stl
77.0 x 45.0 x 36.5

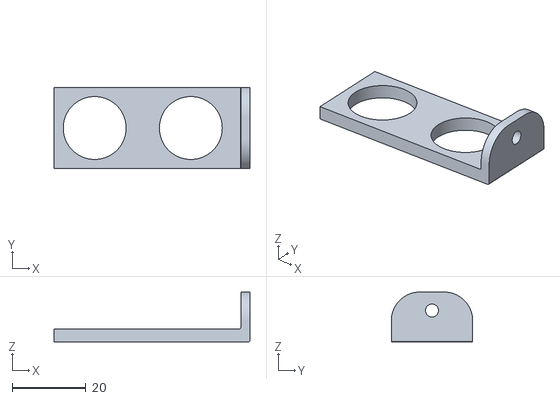
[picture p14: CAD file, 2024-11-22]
models/side sonar mount.stl
53.0 x 22.0 x 13.5

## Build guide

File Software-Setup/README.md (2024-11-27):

## 💻 Software Setup

Our software environment integrates **Arduino IDE** for ESP32 programming and **Raspberry Pi OS** on the Raspberry Pi 4B. Below is the complete guide for setting up the software environment, with all necessary commands and instructions.

---

### 1. Arduino IDE Setup for ESP32 Programming

We use **Arduino IDE** to program the ESP32 microcontroller. Follow these steps:

#### Step 1: Download and Install Arduino IDE
1. Visit the [official Arduino website](https://www.arduino.cc/en/software).
2. Download the version compatible with your operating system.
3. Run the installer and complete the installation process.

#### Step 2: Configure Arduino IDE for ESP32
1. Open the Arduino IDE.
2. Navigate to **File > Preferences**.
3. In the "Additional Boards Manager URLs," paste the following URL:
4. [ESP32 Boards Manager URL](https://raw.githubusercontent.com/espressif/arduino-esp32/gh-pages/package_esp32_index.json)
5. Click **OK**.
6. Go to **Tools > Board > Boards Manager**, search for "ESP32," and click **Install**.

#### Step 3: Verify the Setup
1. Connect your ESP32 via USB.
2. Select the correct board and port under **Tools**.
3. Upload a sample program (e.g., Blink) to test the setup.

---

### 2. Raspberry Pi OS Setup on Raspberry Pi 4B

For this project, we installed **Raspberry Pi OS** on the Raspberry Pi 4B. Here's how to do it:

#### Sub-Step 1: Download Raspberry Pi OS
1. Visit the [official Raspberry Pi website](https://www.raspberrypi.com/software/).
2. Download the Raspberry Pi OS image.

#### Sub-Step 2: Flash Raspberry Pi OS to an SD Card
1. Download and install **Raspberry Pi Imager** from [here](https://www.raspberrypi.com/software/).
2. Insert your SD card into the computer.
3. Open Raspberry Pi Imager and:
- **Select Operating System**: Choose the Raspberry Pi OS image you downloaded.
- **Select Storage**: Choose your SD card.
4. Click **Write** to flash the OS onto the SD card.

#### Sub-Step 3: Boot Raspberry Pi OS
1. Insert the SD card into the Raspberry Pi 4B.
2. Connect peripherals (monitor, keyboard) and power up the Raspberry Pi.
3. Follow the on-screen instructions to complete the Raspberry Pi OS setup.

---

### 3. Installing Python on Raspberry Pi OS

Python is essential for running scripts and software. Install it by running the following commands:

| **Command** | **Description** |
|---|---|
| `sudo apt update` | Updates the system package list. |
| `sudo apt install python3 python3-pip -y` | Installs Python 3 and pip. |

---

### 4. Installing OpenCV and Geany Editor

#### Install OpenCV
To enable computer vision functionalities, install OpenCV:

| **Command** | **Description** |
|---|---|
| `pip3 install opencv-python` | Installs OpenCV. |
| `pip3 install opencv-python-headless` | Installs a lightweight version of OpenCV. |

#### Install Geany Editor
We used **Geany**, a lightweight IDE, for programming:

| **Command** | **Description** |
|---|---|
| `sudo apt install geany -y` | Installs Geany editor. |

---

### 5. Remote Access with RealVNC

To remotely access the Raspberry Pi, we used **RealVNC**. Here's the setup process:

#### Step 1: Install RealVNC
Run the following commands:

| **Command** | **Description** |
|---|---|
| `sudo apt update` | Updates the system package list. |
| `sudo apt install realvnc-vnc-server realvnc-vnc-viewer -y` | Installs RealVNC. |

#### Step 2: Enable VNC
Enable VNC via the Raspberry Pi configuration tool:

| **Command** | **Description** |
|---|---|
| `sudo raspi-config` | Opens the Raspberry Pi configuration tool.  |

- Navigate to **Interface Options > VNC** and select **Enable**.

#### Step 3: Start the VNC Server
Start the VNC server:

| **Command** | **Description** |
|---|---|
| `vncserver` | Starts the VNC server. |

#### Step 4: Automate VNC Server on Boot
To ensure the VNC server starts automatically on boot, configure the systemd service as shown:

```bash
sudo nano /etc/systemd/system/vncserver@.service

[Unit]
Description=Start VNC Server at user logon
After=syslog.target network.target

[Service]
Type=forking
User=pi
ExecStart=/usr/bin/vncserver :1
ExecStop=/usr/bin/vncserver -kill :1

[Install]
WantedBy=multi-user.target

sudo systemctl enable vncserver@1.service
sudo systemctl start vncserver@1.service

```

### Step 5: Connect Remotely

Find the IP address of the Raspberry Pi by running:

| **Command** | **Description** |
|---|---|
| `hostname -I` | Displays the IP address of the Raspberry Pi. |

1. Open **RealVNC Viewer** on your computer.
2. Enter the IP address (e.g., `192.168.x.x`) in the connection bar.
3. Log in using the VNC password you set during configuration.

---

### Summary of Installed Components

| **Component** | **Purpose** |
|---|---|
| **Raspberry Pi OS** | Operating system for the Raspberry Pi 4B. |
| **Arduino IDE** | Programming the ESP32 microcontroller. |
| **Python** | Programming and script execution. |
| **OpenCV** | Computer vision tasks. |
| **Geany** | Lightweight editor for programming. |
| **RealVNC** | Remote access and control of the Raspberry Pi. |

# Starting up the code on startup in pi 4B

## Running Code at Startup Using Crontab

To ensure your script or program runs automatically when the Raspberry Pi boots up, follow these steps:

### Step 1: Edit Crontab
Open the crontab configuration file by running the following command:
```bash
crontab -e
```

Step 2: Add a Startup Command
Add the following line to the crontab

```
@reboot /usr/bin/python3 /path/to/your_script.py

```

### Step 3: Save and Exit
To save and exit the editor (assuming `nano` is used):

- Press `CTRL+O` to save the file.
- Press `CTRL+X` to exit the editor.

### Step 4 : Verify Crontab``

```
crontab -l

```
### Step 5 : Reboot the Raspberry Pi
```
sudo reboot

```

### Step 6 : Debugging (Optional)
```
chmod +x /path/to/your_script.py
```

### Check system logs for CRON errors:
```
cat /var/log/syslog | grep CRON
```

### Example :
```

This is the solid README code with each instruction in its own section, formatted clearly for use.

```

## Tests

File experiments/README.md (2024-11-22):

# 🤖 *Our Previous SMOKI**(MODEL -1 )

**SMOKI**, developed by **MAYERDOA ROBOTICS**, represents one of our earlier robotic innovations. This guide provides step-by-step instructions, visual aids, and tips for assembling the bot.

---

## 🛠️ 3D Printed Baseplate

baseplate3

The 3D-printed baseplate provides a durable and modular foundation for SMOKI, enabling precise component placement and efficient wiring.

---

## 🛠️ Installation Spacers (M3 35.5 mm spacers)

spacers1
spaces

Spacers ensure proper alignment and balance, simplifying assembly and optimizing SMOKI’s performance.

---

## ⚙️ Motor Installation



Motors are critical for SMOKI’s movement, offering durability and precise control. Secure installation minimizes vibrations and ensures smooth operation.

---

## 🔧 Rear Axle Gear Assembly

RAA1

The rear axle assembly delivers torque and drive, ensuring stability and efficient power transfer for smooth mobility.

---

## 🛠️ Ackermann Steering System Assembly

AxleCoupler1

This system provides SMOKI with precise steering and dynamic navigation capabilities.

---

## 🖥️ Main PCB Overview

PCB

The PCB integrates all electronic components, ensuring efficient power management and clear communication for reliable operation.

---

# FINAL LOOK

finallook

---

**SMOKI** stands as a milestone in our robotics journey. For our latest innovations, stay connected with **MAYERDOA ROBOTICS**!

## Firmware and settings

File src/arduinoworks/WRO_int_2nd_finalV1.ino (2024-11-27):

#include <ESP32Servo.h>  // Library for controlling servos on the ESP32
#include <Arduino.h>  // Main Arduino library

// Definitions
#define str 32  // Pin for steering servo
#define mf 27  // Pin for motor forward
#define mb 26  // Pin for motor backward
#define ms 14  // Pin for motor speed control
#define buz 13  // Pin for buzzer
#define sw 4  // Pin for switch input
#define ENCODER_PIN_A 34  // Pin for encoder A channel
#define ENCODER_PIN_B 35  // Pin for encoder B channel
#define fp 25  // Pin for forward proximity sensor
#define rp 23  // Pin for right proximity sensor
#define lp 33  // Pin for left proximity sensor
#define reset_timer 1800  // Timer reset value
#define sinit 95  // Initial steering position
#define led 15  // Pin for LED

// Variables for timers and control flags
unsigned long mun_tmr = 0;
bool tadd = 0;
bool srll = 0;
bool ut = 0;
bool f1 = 0, f2 = 0;
float x_pos = 0, y_pos = 0;
unsigned long lastPosTmr;
volatile long lastEnc = 0;

// Servo and Motor Control
Servo steering;  // Servo object for steering control

float total_angle = 0, initial_angle = 0, last_angle = 0, angle = 0, current_should_angle = 0, target_angle = 0;

// Encoder-related Variables
volatile long encoderCount = 0;  // Counter for encoder pulses
volatile long lastencoderCount = 0;
volatile int lastStateA;

// PID Control Parameters
float Kp = 3;  // Proportional gain
float Ki = 0;  // Integral gain
float Kd = 0.2;  // Derivative gain
float previousError = 0;  // Previous error for PID calculation
float integral = 0;  // Integral term for PID
int steeringAngle;  // Calculated steering angle
float correction;  // Correction value from PID
float error;  // Error value for PID control

// Timers and Delays
unsigned long s_timer = 0;
unsigned long timer = 0;
unsigned long stop_timer = 0;
unsigned long srl_timer = 0;
unsigned long orientation_timer = 0;
unsigned long wait_timer = 0;
unsigned long sonar_timer = 0;
unsigned long srlt_timer = 0;

// Line and Object Detection
int obj;
bool line_dect = 1;  // Line detection flag
bool should_stop = 0;  // Flag to indicate stopping
bool orientation_check = 0;
bool millis_count = 0;
bool left = 0;
int is_obj = 0;
int objstr = 100;
int laststr = 0;
int turn = 0;
int new_srl = 0;
int steering_table[42];  // Array to store steering values

// Flags and States
bool gpass = 0;
bool rpass = 0;
unsigned long m1;

short int fd, ld, rd;  // Distance measurements from sensors
char int_it;

int return_timer = 0;
int max_possible_str = 35;

TaskHandle_t handleSensor;  // Task handle for dual-core processing

// Interrupt Service Routine for Encoder
void IRAM_ATTR handleEncoderA() {
  int stateA = digitalRead(ENCODER_PIN_A);  // Read the current state of encoder pin A
  int stateB = digitalRead(ENCODER_PIN_B);  // Read the current state of encoder pin B

  // Update encoder count based on the states of encoder pins A and B
  if (stateA != lastStateA) {
    if (stateA == HIGH) {
      if (stateB == LOW) {
        encoderCount++;
      } else {
        encoderCount--;
      }
    } else {
      if (stateB == HIGH) {
        encoderCount++;
      } else {
        encoderCount--;
      }
    }
  }
  lastStateA = stateA;  // Update last state of pin A
}

void setup() {
  Serial.begin(115200);  // Initialize serial communication at 115200 baud rate
  Serial2.begin(115200);  // Initialize Serial2 for additional communication
  ledcSetup(15, 1000, 8);  // Setup LED control channel
  ledcAttachPin(14, 15);  // Attach motor speed pin to channel
  ledcWrite(15, 255);  // Set initial motor speed

  steering.attach(str, 500, 2500);  // Attach steering servo to pin and set pulse width range
  steering.write(sinit);  // Set steering to initial position

  xTaskCreatePinnedToCore(dualcore, "secondJob", 4096, NULL, 1, &handleSensor, 0);  // Create a task on the second core

  lastStateA = digitalRead(ENCODER_PIN_A);  // Read the initial state of encoder pin A

  // Initialize steering table values
  steering_table[20] = 95;
  double pt = 7.0 / 4.0;
  double tnc = 0;
  double vla;
  for (int i = 19; i >= 0; i--) {
    tnc += 1;
    vla = tnc * pt;
    if (vla - floor(vla) > 0.5)
      vla = floor(vla) + 1;
    steering_table[i] = steering_table[20] - vla;
  }
  tnc = 0;
  for (int i = 21; i <= 40; i++) {
    tnc += 1;
    vla = tnc * pt;
    if (vla - floor(vla) > 0.5)
      vla = floor(vla) + 1;
    steering_table[i] = steering_table[20] + vla;
  }

  // Set pin modes for encoder, motor, and other components
  pinMode(ENCODER_PIN_A, INPUT_PULLUP);
  pinMode(ENCODER_PIN_B, INPUT_PULLUP);
  pinMode(mf, OUTPUT);
  pinMode(mb, OUTPUT);
  pinMode(buz, OUTPUT);
  pinMode(sw, INPUT_PULLUP);
  pinMode(led, OUTPUT);

  Serial2.flush();  // Clear Serial2 buffer
}

void loop() {
  int r = button_read();  // Read button state
  if (r == 1) {
    nd();  // Call nd function if button state is 1
  } else if (r == 2) {
    while (1) {
      sonar_read();  // Continuously read sonar sensor
      if (digitalRead(sw) == 0)  // Exit loop if switch is pressed
        break;
    }
  } else if (r == 3) {
    go(100, 160);  // Call go function with distance and speed parameters
  }
}

void dualcore(void * param) {
  // Task to be run on the second core
  while (true) {
    delay(2);  // Delay to prevent high CPU usage
    srl();  // Call srl function
    srl2();  // Call srl2 function
  }
}

void go(int dis, int spd) {
  int turo = dis * 25;  // Calculate target encoder count based on distance
  encoderCount = 0;  // Reset encoder count
  attachInterrupt(digitalPinToInterrupt(ENCODER_PIN_A), handleEncoderA, CHANGE);  // Attach interrupt for encoder

  while (abs(encoderCount) < turo) {
    run(spd);  // Run motor at specified speed
  }
  run(-150);  // Reverse motor briefly to stop
  delay(50);  // Short delay
  run(0);  // Stop motor
  detachInterrupt(digitalPinToInterrupt(ENCODER_PIN_A));  // Detach encoder interrupt
}  // End of go function

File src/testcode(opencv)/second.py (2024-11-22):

import cv2 as cv
import time
import math
import numpy as np
import serial

from aehhhh import neon_color

# import board
# import busio
# from adafruit_ssd1306 import SSD1306_I2C
#from PIL import Image, ImageDraw, ImageFont

# Initialize I2C
#i2c = busio.I2C(board.SCL, board.SDA)

# Initialize the OLED display with the correct address and size (update if needed)
#oled = SSD1306_I2C(128, 64, i2c, addr=0x3C)  # Replace 0x3C with your OLED's address if different

#ser = serial.Serial("/dev/ttyACM0", 115200, timeout=1)

#ser.setDTR(False)
#time.sleep(1)
#ser.flushInput()
#ser.setDTR(True)
#time.sleep(2)

test = cv.VideoCapture(1)

# Infinite loop to check if the camera is successfully opened
while not test.isOpened():
    print("Camera not opened. Retrying...")
    time.sleep(2)  # Wait for 2 seconds before retrying
    test.open(0)  # Try to reopen the camera

print("Camera opened successfully!")

test.set(3, 640)
test.set(4, 420)

LineColors = [[0, 35, 68, 84, 168, 226],
              [98, 40, 93, 122, 112, 159]]
LineValues = [[40, 43, 94],
              [110, 70, 45]]
myColors = [[179, 255, 255, 0, 0, 0],
            [34, 65, 23, 80, 205, 62],
            [110, 160, 98, 129, 214, 136]]
myColorValues = [[19, 78, 50],
                 [186, 49, 65]]  # BGR

neon_color = (57, 255, 20)
frame_cc = np.zeros((480, 640, 3), dtype=np.uint8)  # A 300x640 blank frame
frame_cc[:] = neon_color

# Neon green background in BGR format

or_tnc = 0
or_val = 0
bl_tnc = 0
bl_val = 0

myPoints = []  # [x, y, h, w, colorId]
width_for_constant_distance = 12  # minimum acceptable width
width_for_black_distance = 64
maximum_y_for_object = 82
x_boundary_for_red = 40
x_boundary_for_green = 600

is_obj = 0
obj_w = 0
obj_x = 0

# for turn
object_maximum_width = 62
object_minimum_width = 25
# red tuning
x_boundary_for_red = 40
red_left = 150
red_right = 640

# green tuning
x_boundary_for_green = 600
green_left = 0
green_right = 490

obj_dist_ratio = object_maximum_width - object_minimum_width
obj_depth = green_right - green_left
turning_radius = 0

def draw_rounded_rectangle(draw, x1, y1, x2, y2, radius, outline, width):
    """
    Draw a rounded rectangle.
    draw: ImageDraw object
    x1, y1, x2, y2: Coordinates of the bounding box (top-left and bottom-right)
    radius: Radius of the rounded corners
    outline: Color of the outline
    width: Line width
    """
    # Draw the 4 corners as circles (arcs) and the 4 sides as lines
    draw.arc([x1, y1, x1 + 2 * radius, y1 + 2 * radius], start=180, end=270, fill=outline,
             width=width)  # top-left corner
    draw.arc([x2 - 2 * radius, y1, x2, y1 + 2 * radius], start=270, end=360, fill=outline,
             width=width)  # top-right corner
    draw.arc([x1, y2 - 2 * radius, x1 + 2 * radius, y2], start=90, end=180, fill=outline,
             width=width)  # bottom-left corner
    draw.arc([x2 - 2 * radius, y2 - 2 * radius, x2, y2], start=0, end=90, fill=outline,
             width=width)  # bottom-right corner

    # Draw the 4 sides of the rectangle
    draw.line([x1 + radius, y1, x2 - radius, y1], fill=outline, width=width)  # top side
    draw.line([x1 + radius, y2, x2 - radius, y2], fill=outline, width=width)  # bottom side
    draw.line([x1, y1 + radius, x1, y2 - radius], fill=outline, width=width)  # left side
    draw.line([x2, y1 + radius, x2, y2 - radius], fill=outline, width=width)  # right side


# Example usage in your display_message function:
def display_message(line1, line2, line3, font_size=10):
    try:
        font = ImageFont.truetype("/usr/share/fonts/truetype/dejavu/DejaVuSans-Bold.ttf", font_size)
    except IOError:
        font = ImageFont.load_default()

    # Create an image to draw on
    image = Image.new("1", (oled.width, oled.height))
    draw = ImageDraw.Draw(image)

    # Helper function to draw a centered text
    def draw_centered_text(text, y_offset):
        text_width, text_height = draw.textsize(text, font=font)
        x = (oled.width - text_width) // 2  # Center the text
        draw.text((x, y_offset), text, font=font, fill=255)

    # Clear the screen by filling it with black
    draw.rectangle((0, 0, oled.width, oled.height), outline=0, fill=0)

    # Draw a border with rounded corners around the screen
    border_margin = 2
    draw_rounded_rectangle(draw, border_margin, border_margin, oled.width - border_margin, oled.height - border_margin,
                           10, outline=255, width=2)

    # Draw the title line
    draw_centered_text("Mayerdoa_Robotics", 6)  # Title line at the top

    # Draw the three lines with appropriate vertical spacing
    draw_centered_text(line1, font_size + 8)  # First line
    draw_centered_text(line2, 2 * font_size + 10)  # Second line (depends on variable d)
    draw_centered_text(line3, 3 * font_size + 12)  # Third line (depends on variable e)

    # Display the image on the OLED
    oled.image(image)
    oled.show()


def convert(k):
    res = 0
    if k > 240:
        res -= (k - 240)
    else:
        res += abs(k - 240)
    return res

def convert2(k):
    res = 0
    if k > 320:
        res -= (k - 320)
    else:
        res += abs(k - 320)
    return res
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

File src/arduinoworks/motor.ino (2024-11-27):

void run(int speed) {

  if (speed == 0) {
    digitalWrite(mf, 0);      // Turn off the forward motor
    digitalWrite(mb, 0);      // Turn off the backward motor
  }
  // Check if speed is negative (reverse condition)
  else if (speed < 0) {
    digitalWrite(mf, 1); // Set forward motor speed (using absolute value)
    digitalWrite(mb, 0);        // Turn off backward motor
  }
  // Check if speed is positive (forward condition)
  else if (speed > 0) {
    digitalWrite(mf, 0);        // Turn off forward motor
    digitalWrite(mb, 1); // Set backward motor speed (using absolute value)
  }

  ledcWrite(15, int(abs(speed)));
}

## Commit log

2024-09-20 Create AssemblyGuide
2024-09-20 Update AssemblyGuide
2024-09-20 Add files via upload
    Geartopencloser
    [gear top encloser.stl]
2024-09-20 Add files via upload
    SONAR MOUNT AND BACK DRIVE GEARS
    [back drive gear.stl, sonar mount.stl]
2024-09-20 Create model_files(stl)
2024-09-20 Update and rename nn.py to camera_testing.py
